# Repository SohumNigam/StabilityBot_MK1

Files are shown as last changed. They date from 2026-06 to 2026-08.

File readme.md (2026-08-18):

# StabilityBot MK1

*Currently in prototype phase*

A self-balancing two-wheeled robot — an inverted pendulum stabilized
by IMU feedback and PID motor control, being built up toward full
4-state LQR control on a custom PCB.

**Full write-up / showcase:**
[sohumnigam.github.io/projects/stability_bot_MK1.html](https://sohumnigam.github.io/projects/stability_bot_MK1.html)

## Why I built this

I wanted a project that went past the usual "balance a robot with a
PID loop" hobby build — something that let me go deep on control
theory (state-space modeling, LQR, Kalman filtering), embedded
firmware, and PCB design all at once, and end up with a portfolio
piece that shows that depth rather than just a demo video. The
long-term goal is a robot that balances using a full 4-state LQR
controller (θ, θ̇, x, ẋ) on hardware I designed myself, with a
classical-vs-learned comparison against a reinforcement learning
controller down the line.

## Photos

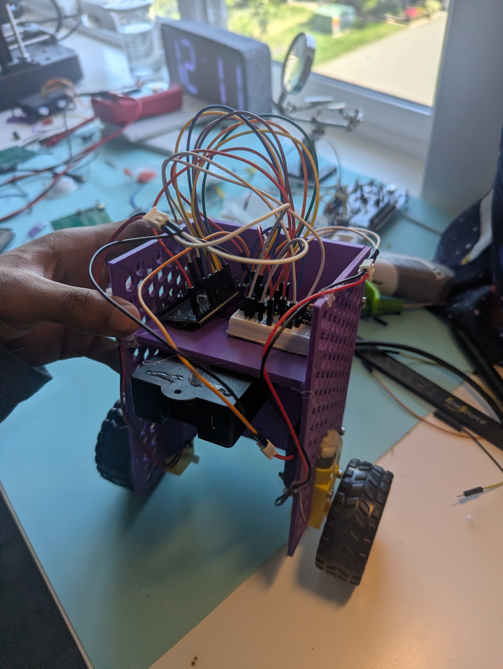
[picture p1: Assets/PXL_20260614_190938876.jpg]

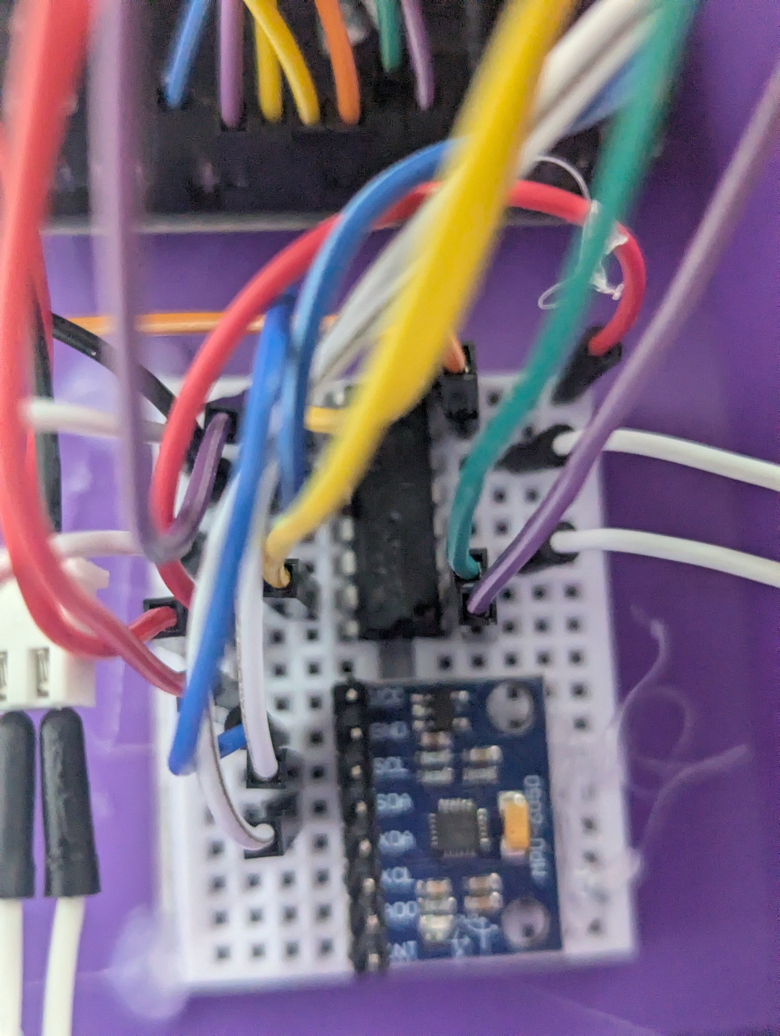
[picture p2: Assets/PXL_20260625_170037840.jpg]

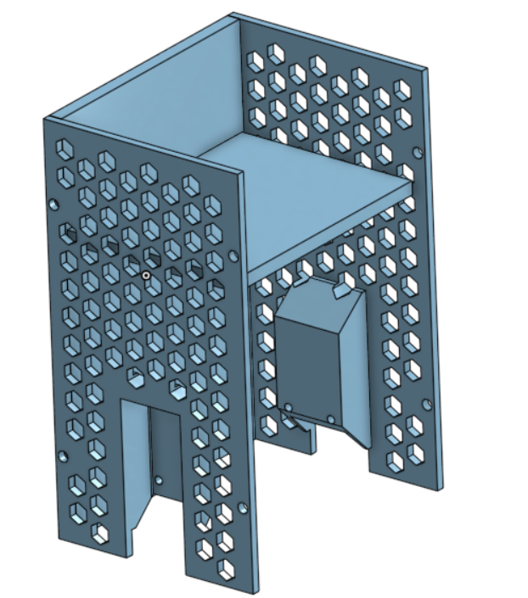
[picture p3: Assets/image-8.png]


## Demo Video

This version used PID to validate the hardware setup and learn about basic control theory. 



Will implement LQR in the future.

## Current Wiring Diagram (Subject to change)
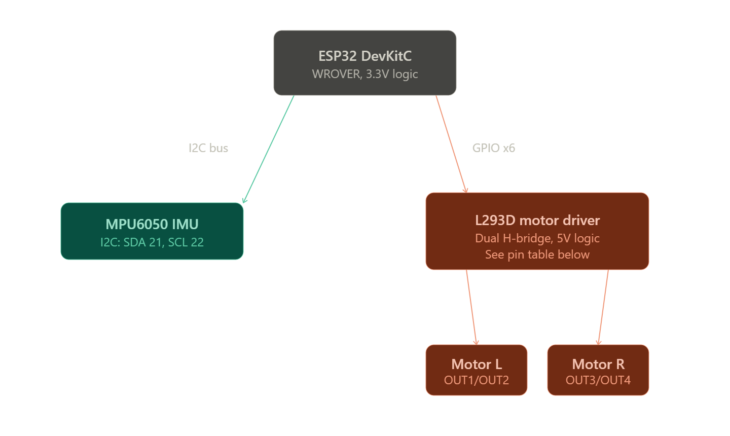
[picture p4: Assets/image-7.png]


## Future Diagram
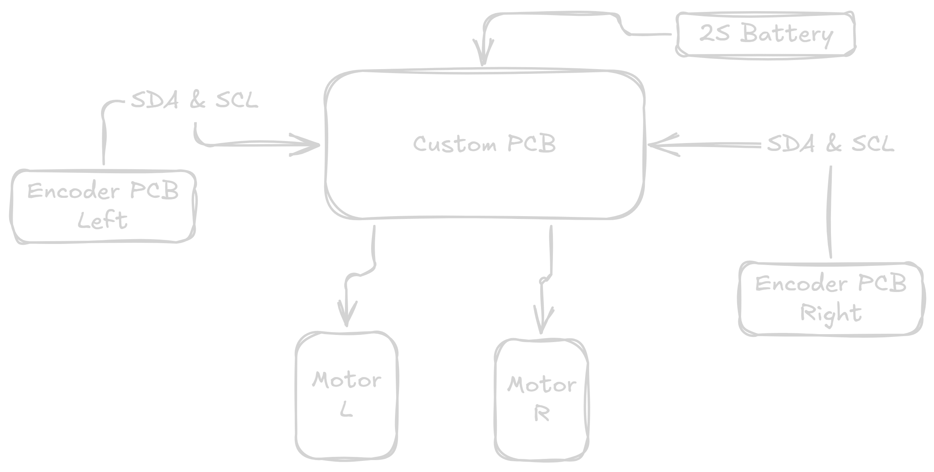
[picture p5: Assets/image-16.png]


## Current Features

- Active motor balancing response
- IMU sensor fusion (complementary filter, Kalman filter in progress)
- PID control loop
- Live web dashboard (WebSocket telemetry: pitch, motor output, PID
  tuning sliders) served from the ESP32 in SoftAP mode

## Hardware Overview

| Component | Current | Planned Upgrade |
|---|---|---|
| Compute | ESP32 Devboard | - |
| IMU | MPU6050 | Bosch BMI320 (SPI) |
| Motor driver | L293D | TB6612FNG |
| Motors | Standard yellow DC geared motors | — |
| Battery | ELEGOO battery pack | Will be compatible with any 2s Battery |
| Chassis | 3D printed | — |
| Encoders | None | AS5600 |

## Software Overview

**FreeRTOS control task**
- IMU readings
- PID calculations (LQR planned once encoders are integrated)
- Motor PWM control

**FreeRTOS web interface task**
- Digital logging
- Mobile control
- Remote PID tuning

## How to Assemble

<!-- TODO: fill in with real steps once chassis/wiring is finalized -->
1. 3D print the chassis (files: hardware/cad/step)
2. Mount motors and wheels using the screws that come with the yellow motors
3. Wire IMU, motor driver, and battery to the ESP32 per the defined pins in main.c (you will need to look in the motor structs for them)
4. Secure battery pack and IMU to minimize vibration noise. I used hot glue for this version.

## How to Flash

1. Clone this repo into your ESP-IDF project directory
2. Confirm your wiring matches the pin assignments in `main/`
3. Build and flash with `idf.py build flash monitor`
4. Connect to the robot's WebSocket dashboard to tune PID live

## Rough Bill of Materials

See the full BOM in BOM.csv. Still a work in progress as some passive parts are not yet finalized.

| Category | Qty | Part | Value | LCSC Part # | Price/unit | Extended Description | Link |
|---|---|---|---|---|---|---|---|
| Compute | 1 | ESP32 WROVER DevKitC | Espressif ESP32-WROVER-DevKitC | $11 | — | Purchased from DigiKey | [DigiKey](https://www.digikey.com/en/products/detail/espressif-systems/ESP32-DEVKITC-VIE/12091811) |
| IMU | 1 | BMI320 IMU | Bosch BMI320 | C22391148 | $0.99 | SPI IMU | [LCSC](https://www.lcsc.com/product-detail/C22391148.html) |
| Mechanics | 2 | Diametric Magnets | — | — | — | Will try to find (Hard to find affordable sources) | [Amazon](https://www.amazon.com/Diametrically-Magnetized-Neodymium-Permanent-Magnet/dp/B0GWXBS6SM) |
| Encoder | 1 | AS5600 Magnetic Encoder | AMS AS5600 | C499458 | $1.1855 | For wheel position tracking | [LCSC](https://www.lcsc.com/product-detail/C499458.html) |
| Motor Driver | 1 | TB6612FNG Motor Driver | Toshiba TB6612FNG | C141517 | $1.1659 | Target PCB driver; STBY tied to GPIO | [LCSC](https://www.lcsc.com/product-detail/C141517.html) |
| Mechanical | 2 | DC Gear Motors | — | $20 | — | Includes wheels | [Amazon](https://www.amazon.ca/SazkJere-Geared-Motor-Gearbox-200RPM/dp/B0G64KFYPS) |
| Mechanical | 1 | Chassis / Frame (custom) | — | — | — | Onshape CAD; STEP in `hardware/cad/step/` | — |

Full robot rough cost ~$170 + shipping

## Known Issues

- IMU signal occasionally drops out on the current breadboard
  prototype — traced to noise from jumper wire connections; largely
  mitigated with twisted GND pairs and a control-loop delay, but not
  fully eliminated. Root fix is the move to a soldered BMI320 board
  and eventually the custom PCB.
- 4-state LQR not yet running on hardware — pending encoder
  integration.

## Credits

- Built on [ESP-IDF](https://github.com/espressif/esp-idf) (Espressif)

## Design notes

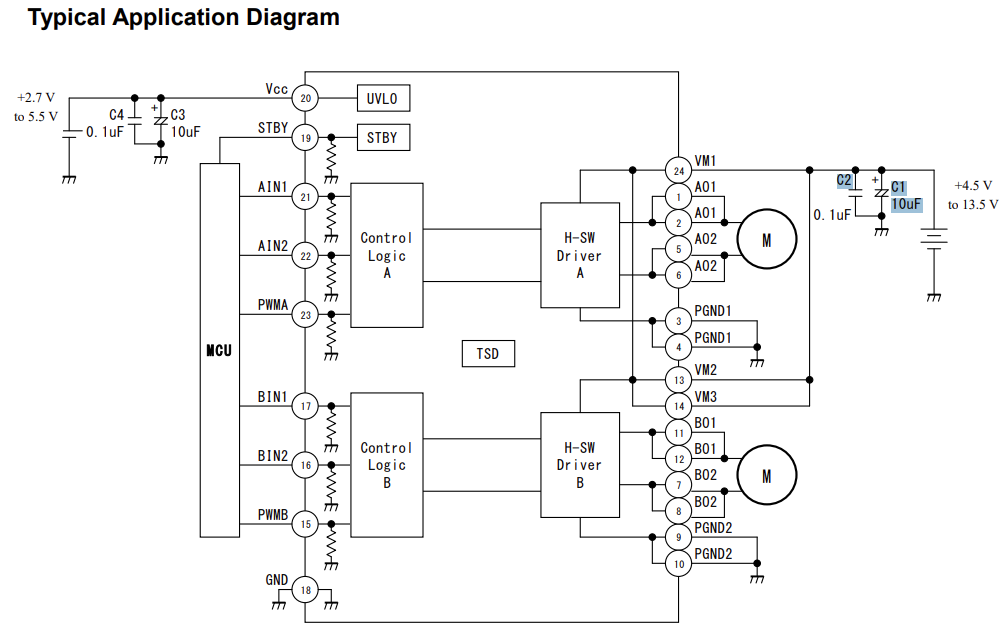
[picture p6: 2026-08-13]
hardware/PCB/TB6612FNG/Assets/Screenshot 2026-07-19 144515.png

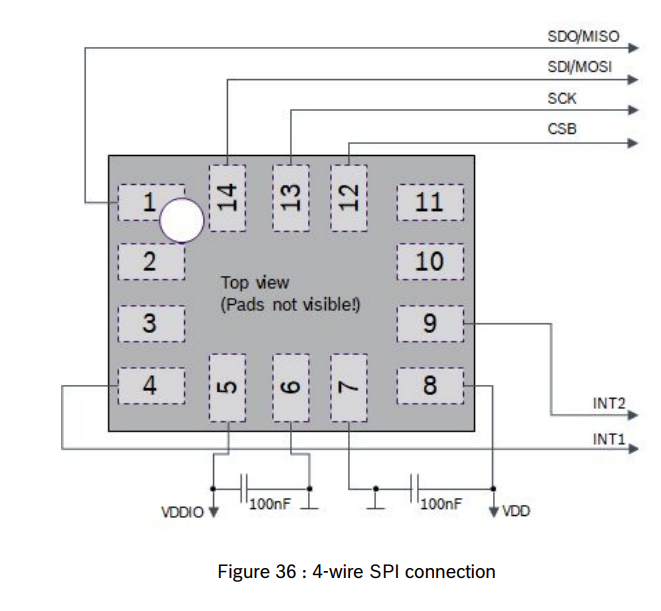
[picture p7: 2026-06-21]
Assets/BMI320_Circuit_Diagram.png

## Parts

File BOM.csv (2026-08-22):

Category | Qty | Part | Value | LCSC Part number | Price/unit | Extended description | Link
Compute | 1 | ESP32 WROVER DevKitC | Espressif ESP32-WROVER-DevKitC |  | $12 | Purchased from digikey | https://www.digikey.com/en/products/detail/espressif-systems/ESP32-DEVKITC-VIE/12091811
IMU | 1 | BMI320 IMU | Bosch BMI320 | C22391148 | $0.99 | SPI IMU | https://www.lcsc.com/product-detail/C22391148.html
Passive | 4 | Capacitor | 100nf | C49678 | $ 0.0218 |  | https://www.lcsc.com/product-detail/C49678.html
Mechanics | 2 | Diametric magnets |  |  |  | Will try to find | https://www.amazon.com/Diametrically-Magnetized-Neodymium-Permanent-Magnet/dp/B0GWXBS6SM?th=1
Encoder | 1 | AS5600 Magnetic Encoder | AMS AS5600 | C499458 | $ 1.1855 | For wheel pos tracking | https://www.lcsc.com/product-detail/C499458.html
 | 1 | Capacitor | 1uf | C28323 | $0.04 |  | https://www.lcsc.com/product-detail/C28323.html?s_z=n_q_t_1uf%25200805
Motor Driver | 1 | TB6612FNG Motor Driver | Toshiba TB6612FNG | C141517 | $ 1.1659 | Target PCB driver; STBY tied to GPIO (to purchase) | https://www.lcsc.com/product-detail/C141517.html
Passive | 2 | Tantalum Capacitor | 10uf | C117023 | $0.31 |  | https://www.lcsc.com/product-detail/C117023.html
Mechanical | 7 | Female header |  | C40877 | $0.09 | To plug in esp32 devboard | https://www.lcsc.com/product-detail/C40877.html
Mechanical | 5 | Male headers |  | C49257 | $ 0.0272 |  | https://www.lcsc.com/product-detail/C49257.html
Mechanical | 2 | DC Gear Motors |  |  | $25 | Includes Wheels | https://www.amazon.ca/SazkJere-Geared-Motor-Gearbox-200RPM/dp/B0G64KFYPS?s=industrial
Mechanical | 1 | Chassis / Frame (custom) |  |  |  | Onshape CAD; STEP in hardware/cad/step/
 |  |  |  |  | TOTAL COST | Sum of (Qty x Price/unit) across all rows

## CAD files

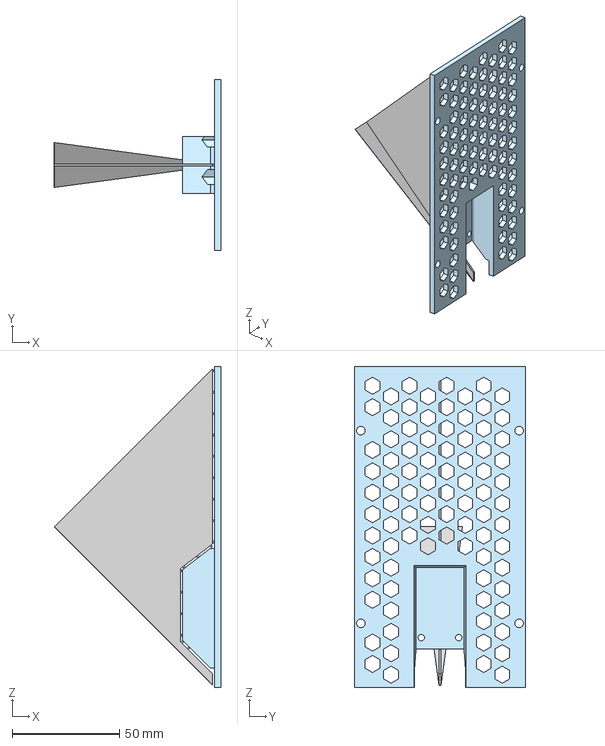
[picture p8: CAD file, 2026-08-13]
hardware/CAD/STEP/Side Plates.step
78.0 x 80.0 x 150.0 mm

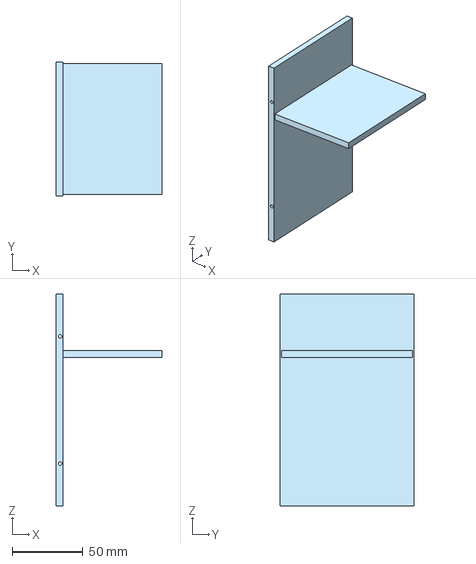
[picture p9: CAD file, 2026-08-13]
hardware/CAD/STEP/Back Plate - Plate.step
75.0 x 95.0 x 150.0 mm

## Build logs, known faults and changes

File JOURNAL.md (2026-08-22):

---
title: "StabilityBot MK1"
author: "sohum"
description: "Self-balancing inverted pendulum robot on ESP32-S3, working toward full 4-state LQR control with a custom PCB"
created_at: "2026-06-10"
---

# Before logging began: Initial concept and first assembly

Built the initial concept with basic IMU-to-motor response firmware
(no PID, no testing chassis yet). Hit the first major bug: the ESP32
boot-looped due to noise on boot GPIO pin 14 — solved by migrating
motor control to pin 25. Iterated quickly on a testing chassis design
in Onshape, then completed the first full assembly of the robot.

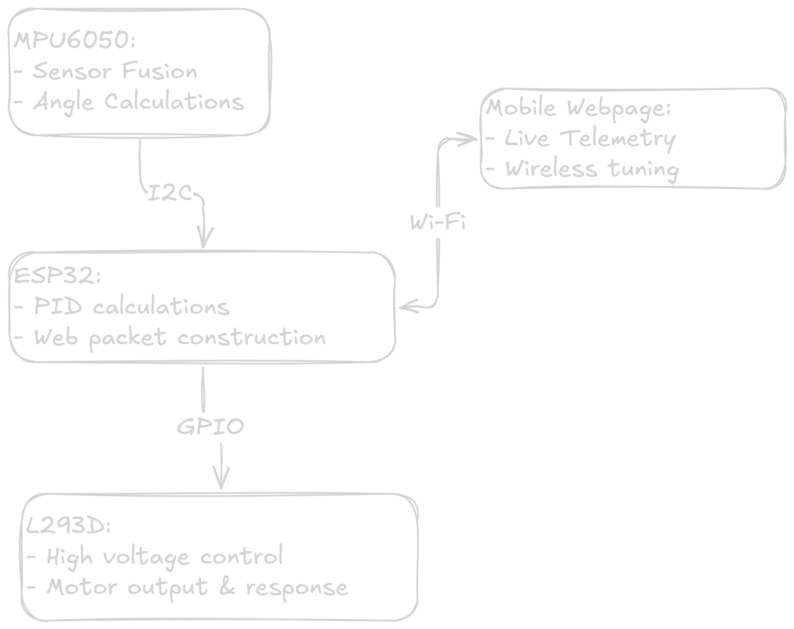
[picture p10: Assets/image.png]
logic diagram


**Total time spent: 8 hours**

# June 10: First balancing test, MPU6050 signal dropouts

Goal: gather initial test results before upgrading to more reliable hardware.

Ran the first balancing test and tried to tune PID. The MPU6050
sensor signal repeatedly cut out, causing laggy, intermittent motor
response. Impossible to tune or balance as a result.

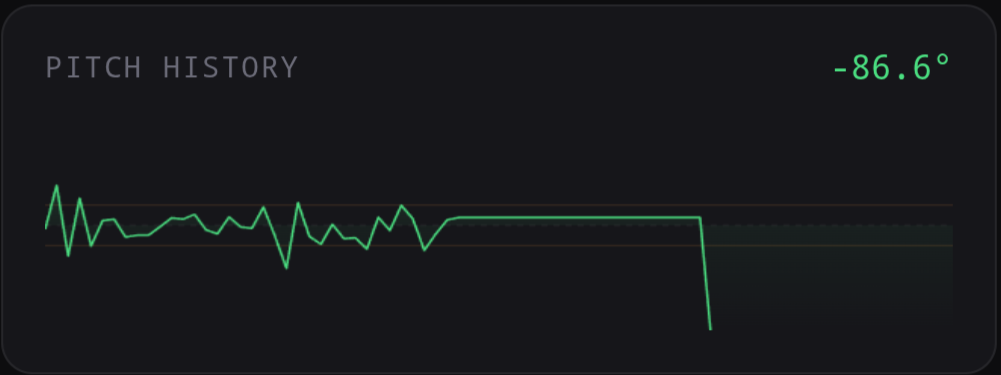
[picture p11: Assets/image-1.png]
signal dropout


Suspected cause: the current breadboard prototype and jumper wire
connections are introducing mechanical and electrical noise, causing
signal drops.

Next step: design and order a BMI320 breakout board and solder
connections to the ESP32 to eliminate testing noise.

**Total time spent: 2 hours**

# June 14: Noise mitigation on the current setup

Goal: investigate what can be done to minimize noise with the
current setup, with intent to carry the findings into the future
design even after the hardware changes.

- Twisted signal wires with GND to reduce noise
- Tuned the complementary filter to smooth the angle estimate

Both changes lowered high-frequency noise and smoothed robot motion.
Signal dropouts still persist, further supporting the need for a
custom PCB.

before:
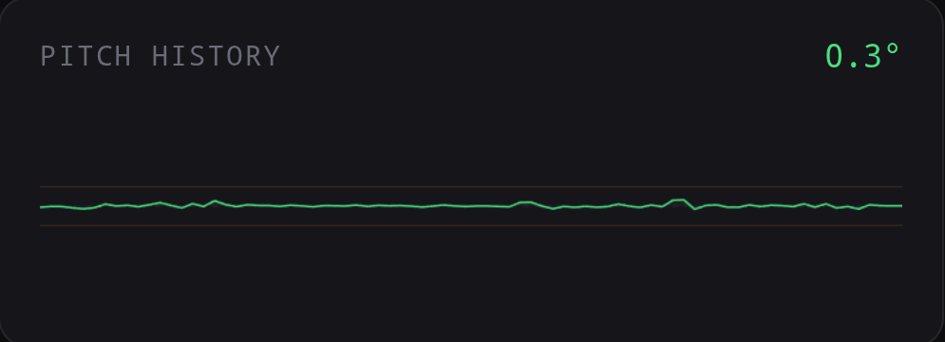
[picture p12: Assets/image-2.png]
noisy imu


after:
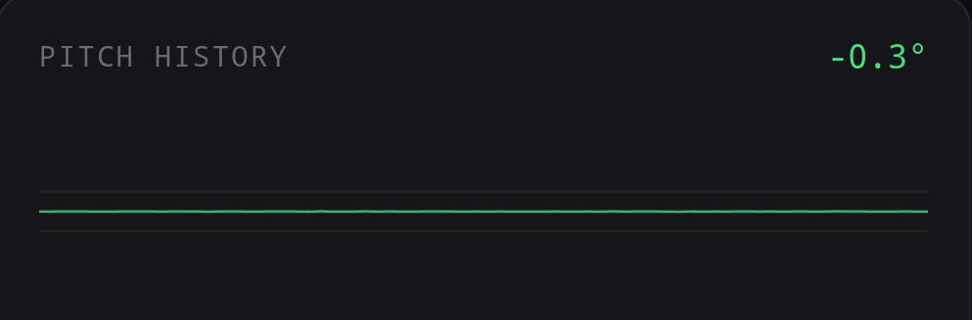
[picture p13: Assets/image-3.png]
smooth imu


**Total time spent: 1 hour**

# June 20: Chasing a software cause for signal dropout

Goal: investigate potential software causes for signal dropout.
signal dropout

- Disabled the motors
- Printed IMU readings to the serial console for debugging
- Discovered occasional watchdog timer triggers
- Added a delay to the control loop

The added delay *significantly* reduced signal dropouts during
balancing, making tuning noticeably easier. Dropouts still occur
sparsely but are much more under control now, allowing balancing
attempts to come much closer to succeeding.

**Total time spent: 2 hours**

# July 19: Custom BMI320 driver and board complete, PCB subsystems in design

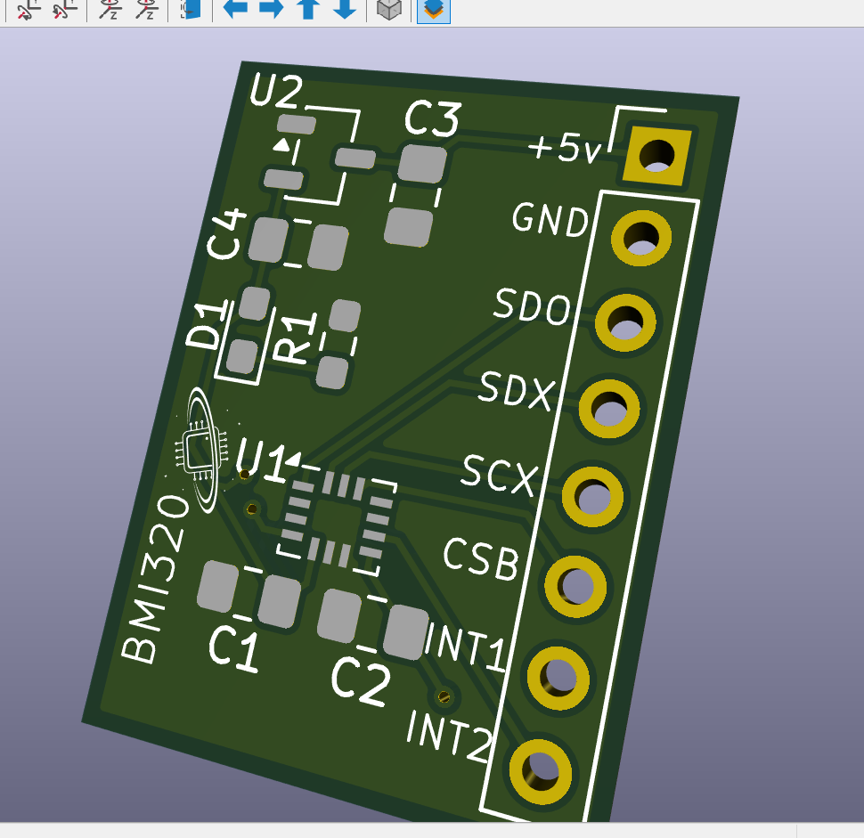
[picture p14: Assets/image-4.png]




BMI320 board debugging is complete and fully functioning. Root cause
was a disconnected VDDIO pin, which prevented the chip from powering
up properly. BMI320 driver firmware is nearing completion and cleanup.

PCB subsystem test boards are now in design (MCU, motor driver,
encoders). Encoders will be used to implement full 4-state LQR control.

Next: reach a fully functioning, fully integrated PCB and begin LQR
implementation.

LQR is short for Linear Quadratic Regulator and is the industry standard for optimal control in state space systems.

Credit to this paper from MIT that helped me learn it:
https://underactuated.mit.edu/lqr.html

**Total time spent: 4 hours**

# Aug 13: PCB subsystems combined into one schematic, Final PCB in design

Combined PCB subsystems into one schematic. Had to resolve a few pin conflicts

BMI320 IMU

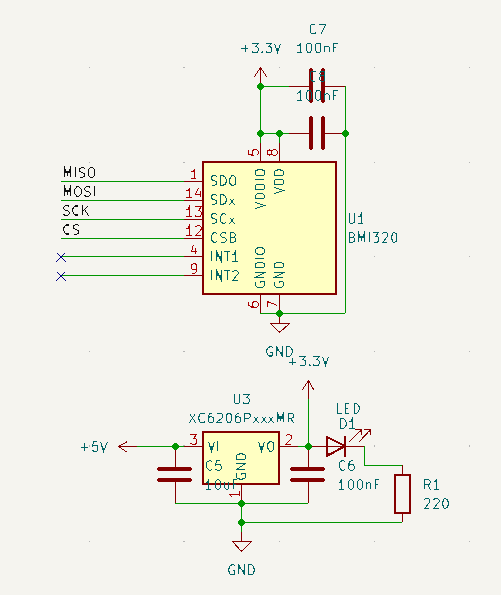
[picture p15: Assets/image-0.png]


Motor driver
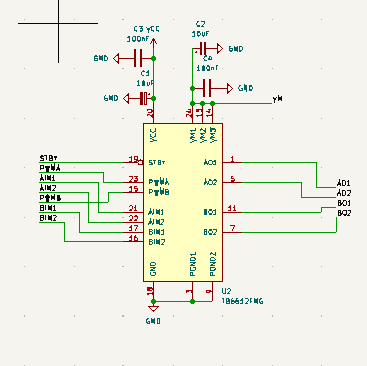
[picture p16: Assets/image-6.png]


Will move on to finalizing and reviweing connections. The start routing the final PCB.
Next steps will be to also finalize magnetic rotary encoder PCB and implement a cad mounting solution. To actually enable Full 4 state LQR control. I have high hpes for the stability of the final robot. Should be significantly more effective than PID.

**Total time spent: 1 hours**

# Aug 16: Putting together a tentative BOM, finalizing schematic, and going down the LQR rabbit hole

While the project is still in progress and not all parts are finalized, I still chose to put together a rough BOM to start to have an idea of what is pending and what can move forward.

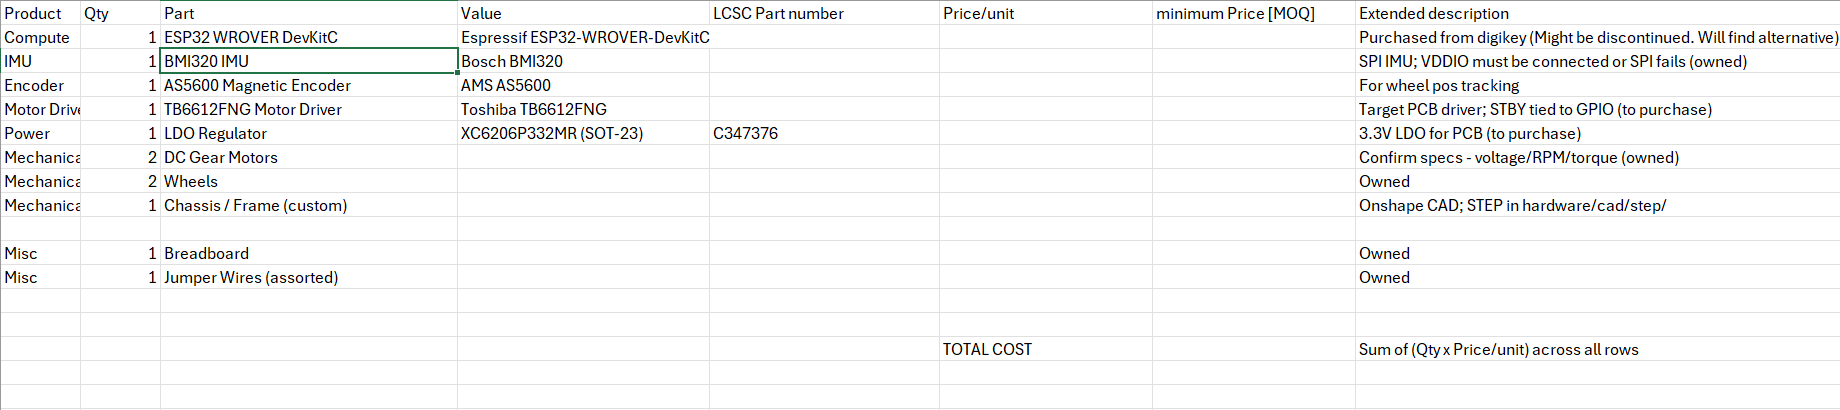
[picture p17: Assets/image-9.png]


Was a pain but I found the exact model of the esp32 board I used without even having it on me (Im on vacation) for the PCB. Also has been added to BOM

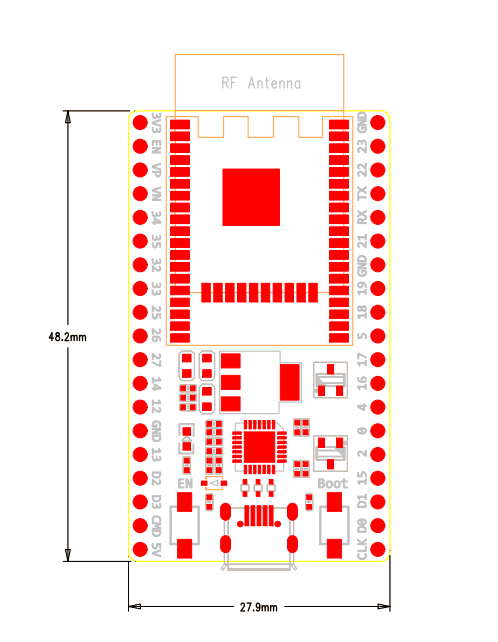
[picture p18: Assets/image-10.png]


With this newfound knowledge, I started finalising the Schematic now that parts are confirmed (just not passive components yet). Super messy rign now will make sure to do LOTS of double checking because I rlly want this to work first try or I might not finish the project in time.

Finalized the schematic!

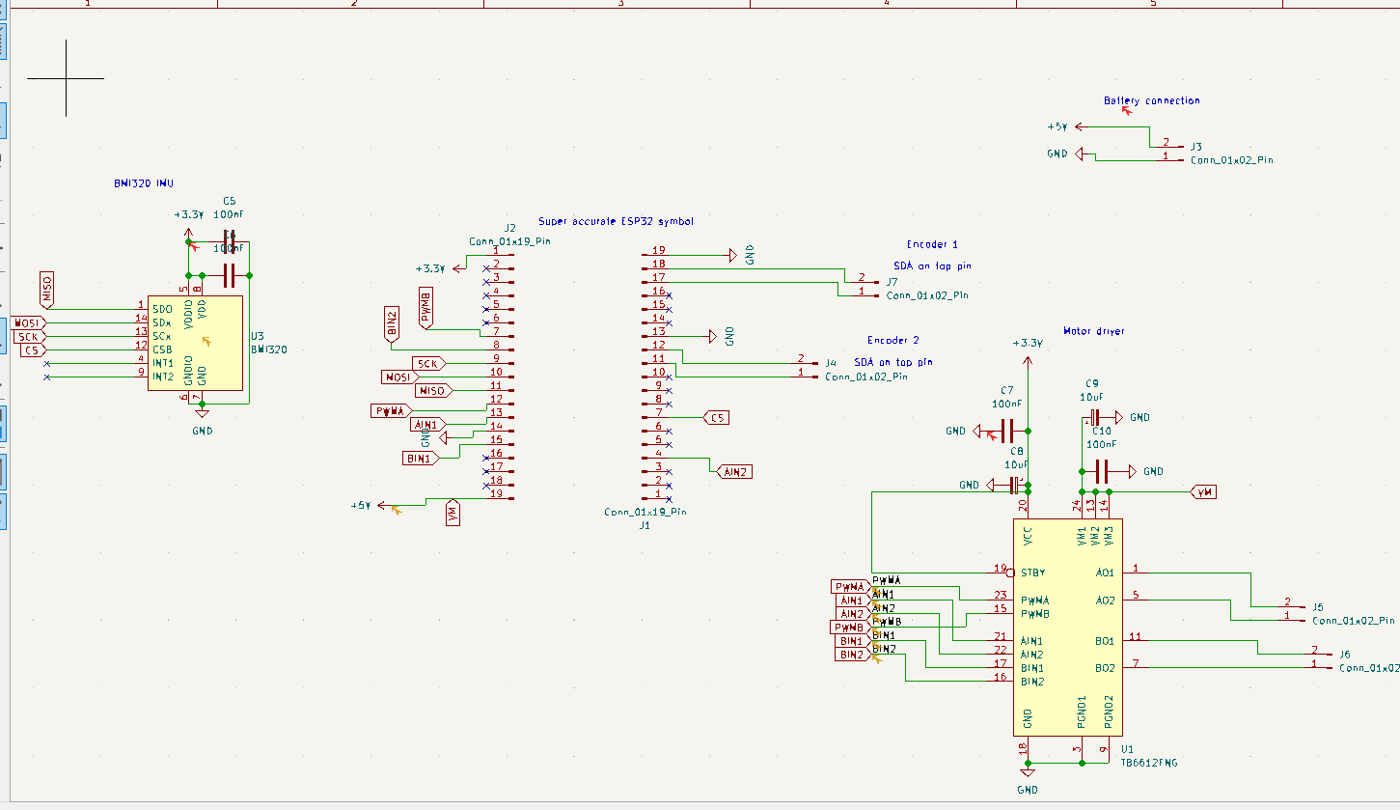
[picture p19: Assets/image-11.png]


Still needs to be revieved and double checked but should be moving on the layout in a day or 2.

Also finished encoder PCB design.

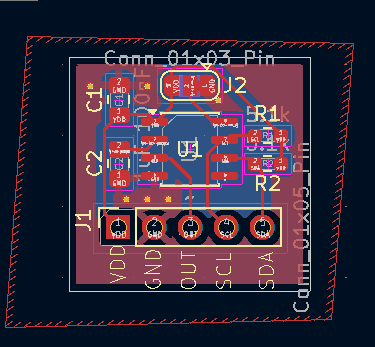
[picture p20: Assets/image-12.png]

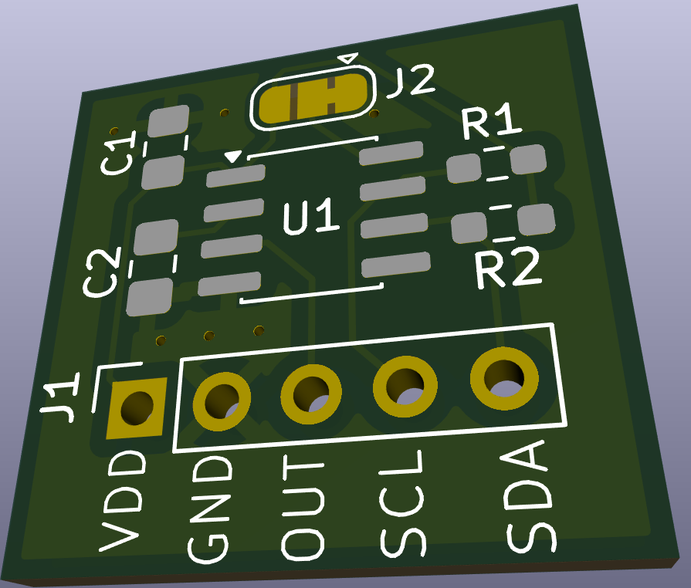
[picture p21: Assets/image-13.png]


Started working on LQR formulas derivation and simulation. Lots of juicy high level math.

The first thing I did was put together what essentially is a simplified writeup covering how LQR will be implmented specifically in my project. There is a lot I don't yet know so expect updates as I learn more about LQR.

To see my writeup about the math behind LQR, go to docs/LQR.md

**Total time spent: 5 hours**

# Aug 17: PCB layout and Started V2 CAD Model

Heres the Layout for the final PCB. Have not reviewed or added silkscreen touchups yet.

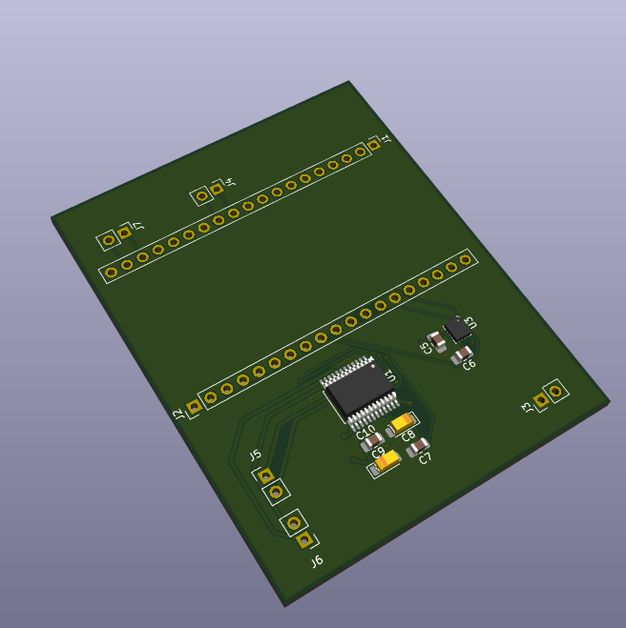
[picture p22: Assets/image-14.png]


Also started designing a sleeker cad model designed to hould the PCB, motors, and battery.
I had to do this without having any of the parts on hand so I also had to spend some time looking online for part dimensions. 

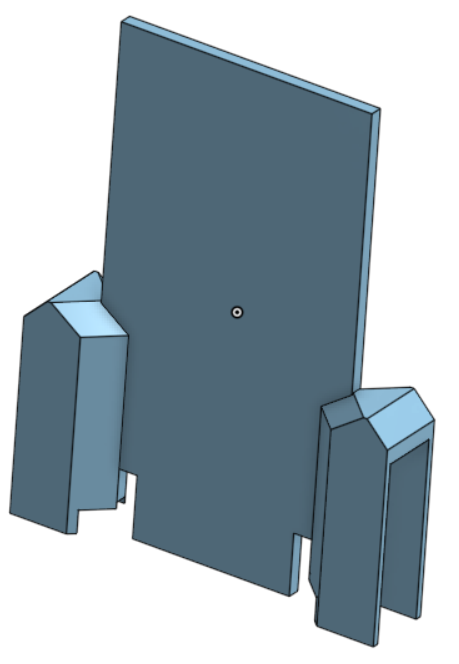
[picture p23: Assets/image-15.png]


Im trying to design the PCB and CAD in paralel to make sure the overall robot is as well put together as possible.

**Total time spent: 2 hours**

# Aug 18: Finalized the PCB!

After triple checking the schematic I polished and cleaned up the PCB layout and it is now ready to order.

I think it looks great!

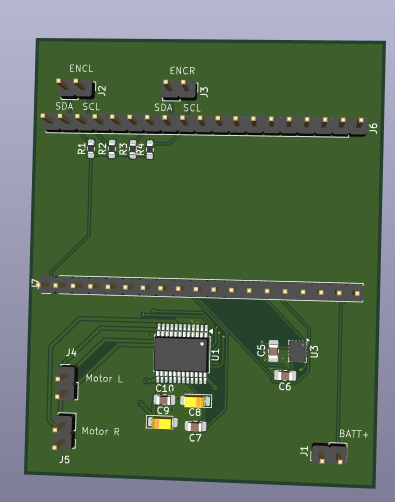
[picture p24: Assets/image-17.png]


Im planning to order it in black to lean into the liquorice theme. Maybe I'll print it with red accents as well I feel like that could look really cool.

I also spent some time working on my readme and BOM to make sure it meets the review requirments.

The BOM only is missing passive components now which will be added soon as I already have them added to my LCSC cart.

Next I need to review the encoder PCB and finally order everything.

**Total time spent: 1 hours**

# Aug 22: Ordered PCBs and almost finished BOM

I ordered both the main PCB board and encoder PCB in black and red respectivley to lean into the Liquorice theme. Honestly I dont think it will look that good but we will have to see

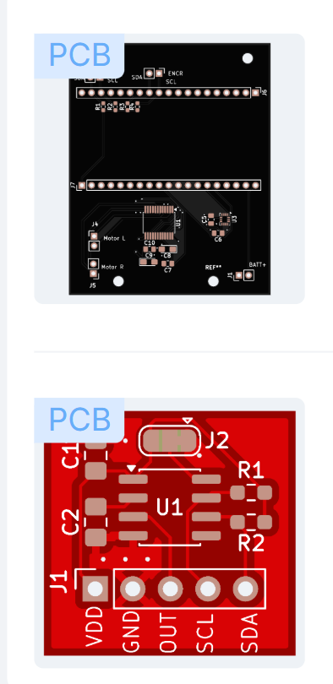
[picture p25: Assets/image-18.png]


**Total time spent: 1 hours**

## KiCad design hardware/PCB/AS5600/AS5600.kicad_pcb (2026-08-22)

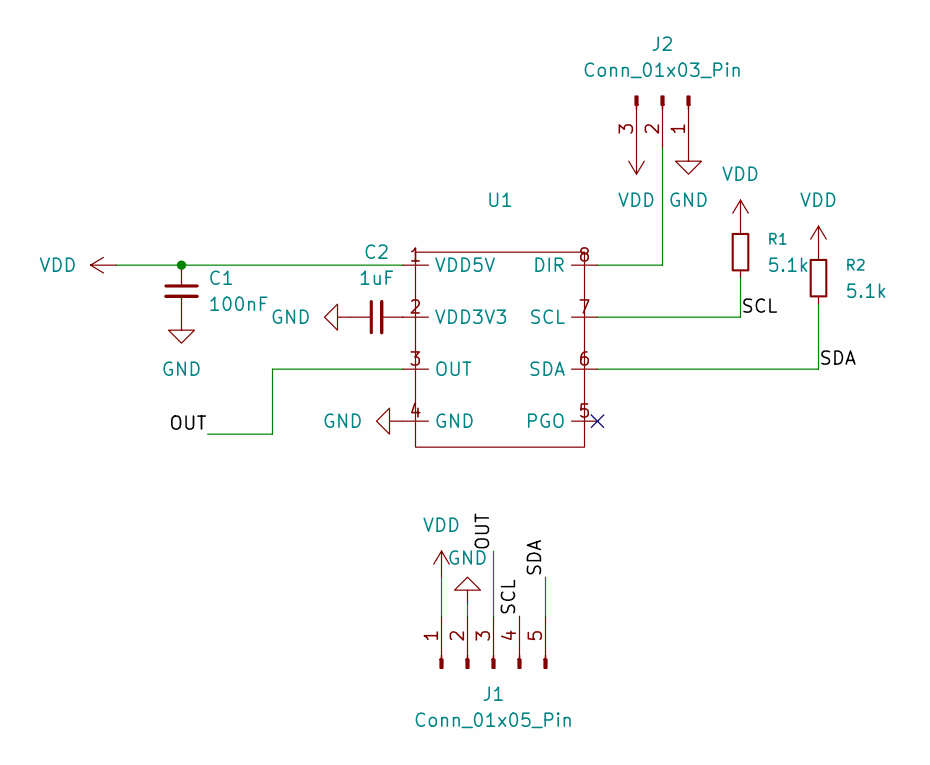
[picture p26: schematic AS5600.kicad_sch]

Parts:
C1: 100nF; C_0805_2012Metric_Pad1.18x1.45mm_HandSolder
C2: 1uF; C_0805_2012Metric_Pad1.18x1.45mm_HandSolder
J1: Conn_01x05_Pin; PinSocket_1x05_P2.54mm_Vertical
J2: Conn_01x03_Pin; SolderJumper-3_P1.3mm_Bridged12_RoundedPad1.0x1.5mm
R1, R2: 5.1k; R_0603_1608Metric_Pad0.98x0.95mm_HandSolder
U1: SOIC-8_3.9x4.9mm_P1.27mm

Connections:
/OUT: J1.3, U1.3 (OUT)
/SCL: J1.4, R1.2, U1.7 (SCL)
/SDA: J1.5, R2.2, U1.6 (SDA)
GND: C1.2, C2.1, J1.2, J2.1, U1.4 (GND)
unnamed: J2.2, U1.8 (DIR)
unnamed: C2.2, U1.2 (VDD3V3)
VDD: C1.1, J1.1, J2.3, R1.1, R2.1, U1.1 (VDD5V)

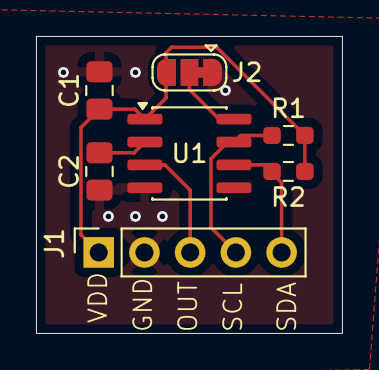
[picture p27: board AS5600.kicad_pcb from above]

Board: 2 copper layers, 17.0 x 16.5 mm, 7 parts (0 on the bottom side), 7 nets.

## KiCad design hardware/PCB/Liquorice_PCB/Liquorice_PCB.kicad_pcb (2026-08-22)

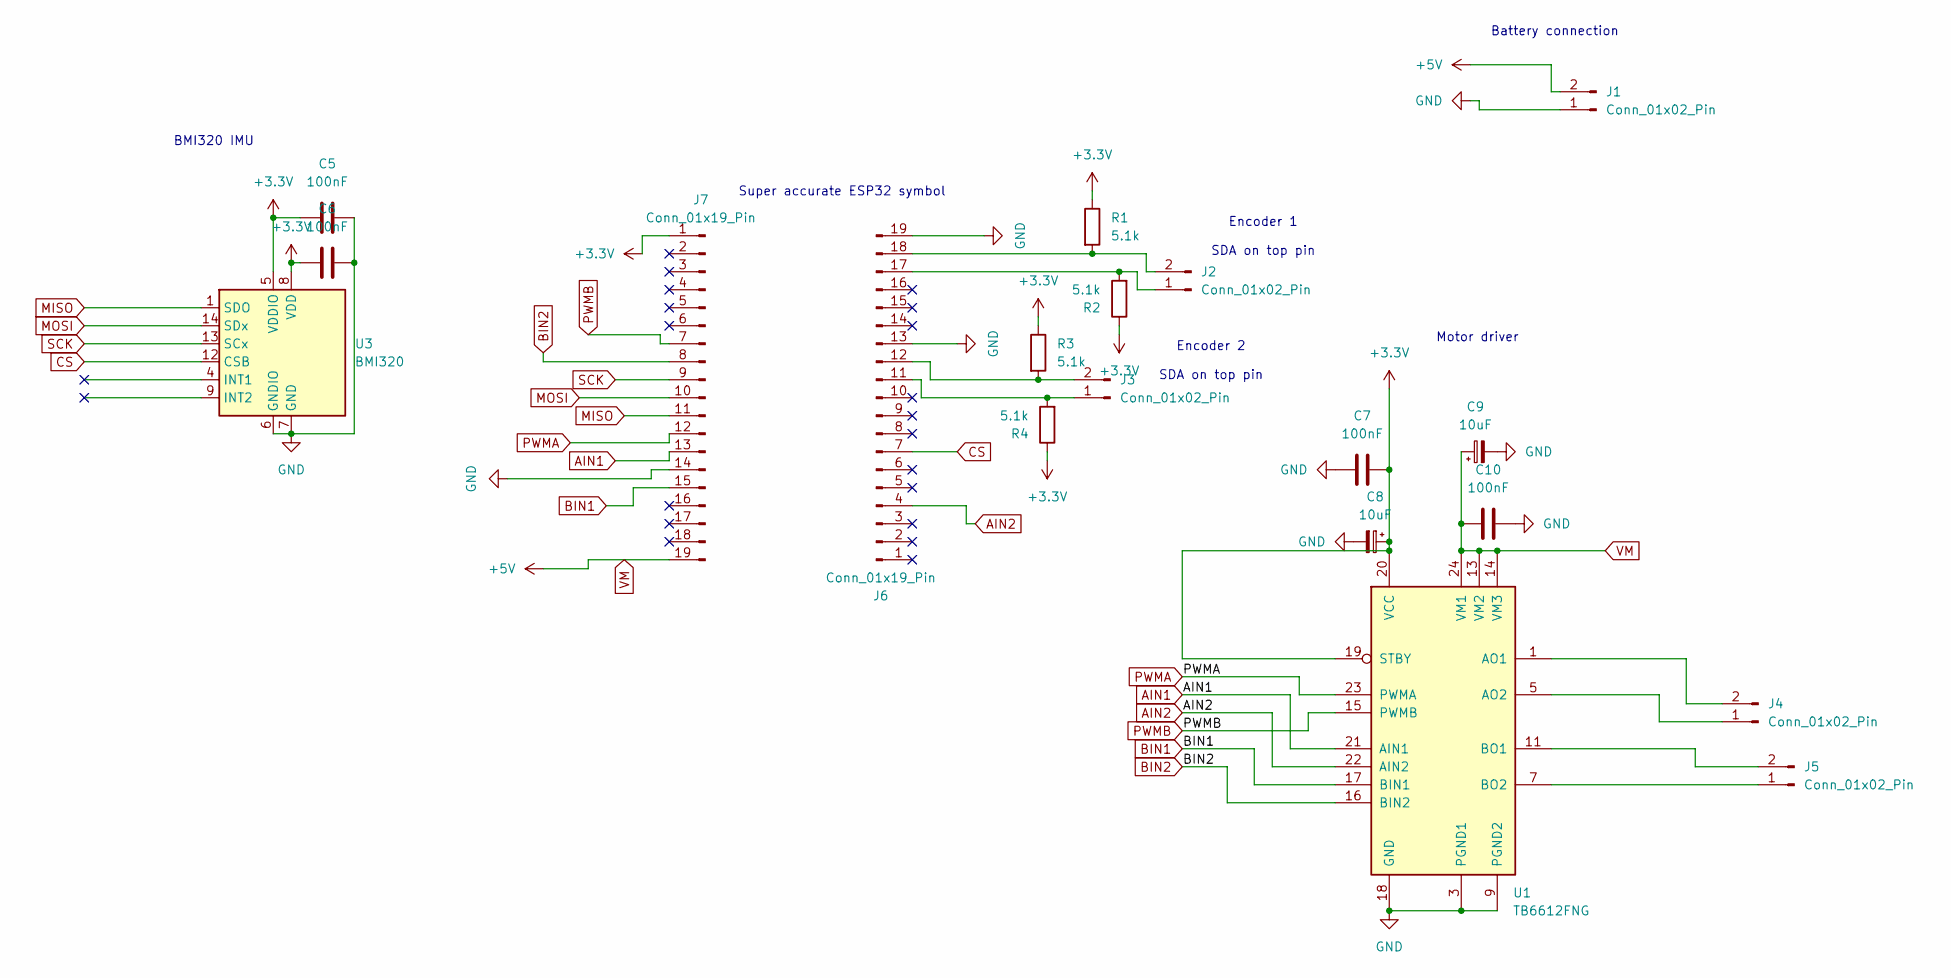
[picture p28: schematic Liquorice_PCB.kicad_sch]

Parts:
C5, C6, C7, C10: 100nF; C_0805_2012Metric_Pad1.18x1.45mm_HandSolder
C8, C9: 10uF; CP_EIA-3216-18_Kemet-A_HandSolder
J1, J2, J3, J4, J5: Conn_01x02_Pin; PinHeader_1x02_P2.54mm_Vertical
J6, J7: Conn_01x19_Pin; PinHeader_1x19_P2.54mm_Vertical
R1, R2, R3, R4: 5.1k; R_0603_1608Metric_Pad0.98x0.95mm_HandSolder
U1: TB6612FNG; SSOP-24_5.3x8.2mm_P0.65mm
U3: BMI320; Bosch_LGA-14_3x2.5mm_P0.5mm

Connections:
+3.3V: C5.1, C6.1, C7.2, C8.1, J7.1, R1.1, R2.1, R3.1, R4.1, U1.19 (STBY), U1.20 (VCC), U3.5 (VDDIO), U3.8 (VDD)
AIN1: J7.13, U1.21 (AIN1)
AIN2: J6.4, U1.22 (AIN2)
BIN1: J7.15, U1.17 (BIN1)
BIN2: J7.8, U1.16 (BIN2)
CS: J6.7, U3.12 (CSB)
GND: C5.2, C6.2, C7.1, C8.2, C9.2, C10.2, J1.1, J6.13, J6.19, J7.14, U1.3 (PGND1), U1.4 (PGND1), U1.9 (PGND2), U1.10 (PGND2), U1.18 (GND), U3.6 (GNDIO), U3.7 (GND)
MISO: J7.11, U3.1 (SDO)
MOSI: J7.10, U3.14 (SDx)
unnamed: J2.1, J6.17, R2.2
unnamed: J2.2, J6.18, R1.2
unnamed: J3.1, J6.11, R4.2
unnamed: J3.2, J6.12, R3.2
unnamed: J4.1, U1.5 (AO2), U1.6 (AO2)
unnamed: J4.2, U1.1 (AO1), U1.2 (AO1)
unnamed: J5.1, U1.7 (BO2), U1.8 (BO2)
unnamed: J5.2, U1.11 (BO1), U1.12 (BO1)
PWMA: J7.12, U1.23 (PWMA)
PWMB: J7.7, U1.15 (PWMB)
SCK: J7.9, U3.13 (SCx)
VM: C9.1, C10.1, J1.2, J7.19, U1.13 (VM2), U1.14 (VM3), U1.24 (VM1)

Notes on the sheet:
Encoder 1 SDA on top pin
Motor driver
BMI320 IMU
Super accurate ESP32 symbol
Battery connection
Encoder 2 SDA on top pin

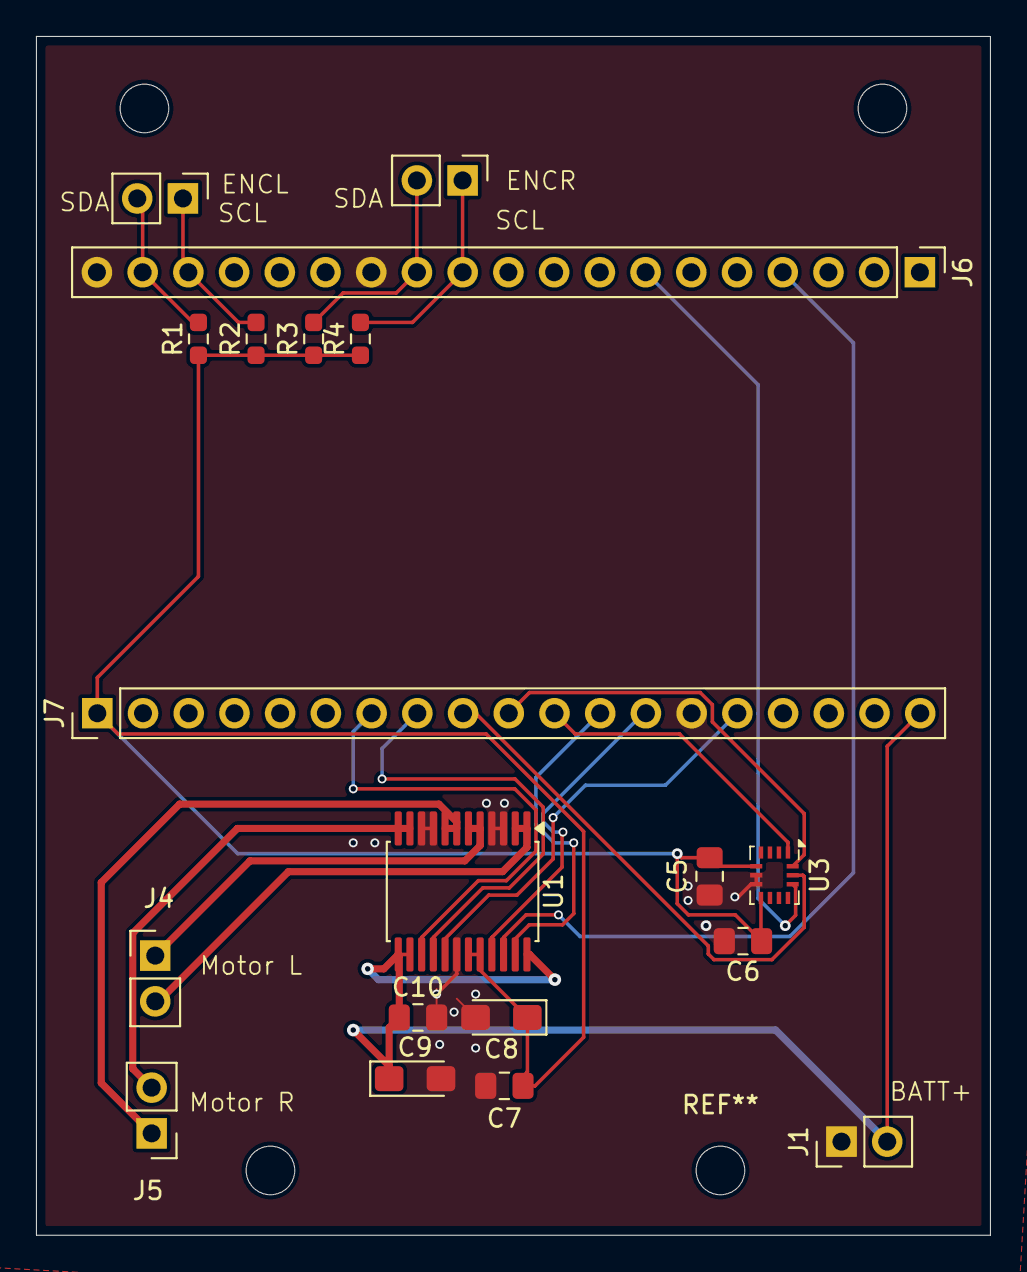
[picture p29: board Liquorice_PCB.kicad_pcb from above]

Board: 2 copper layers, 53.0 x 66.6 mm, 19 parts (0 on the bottom side), 21 nets.

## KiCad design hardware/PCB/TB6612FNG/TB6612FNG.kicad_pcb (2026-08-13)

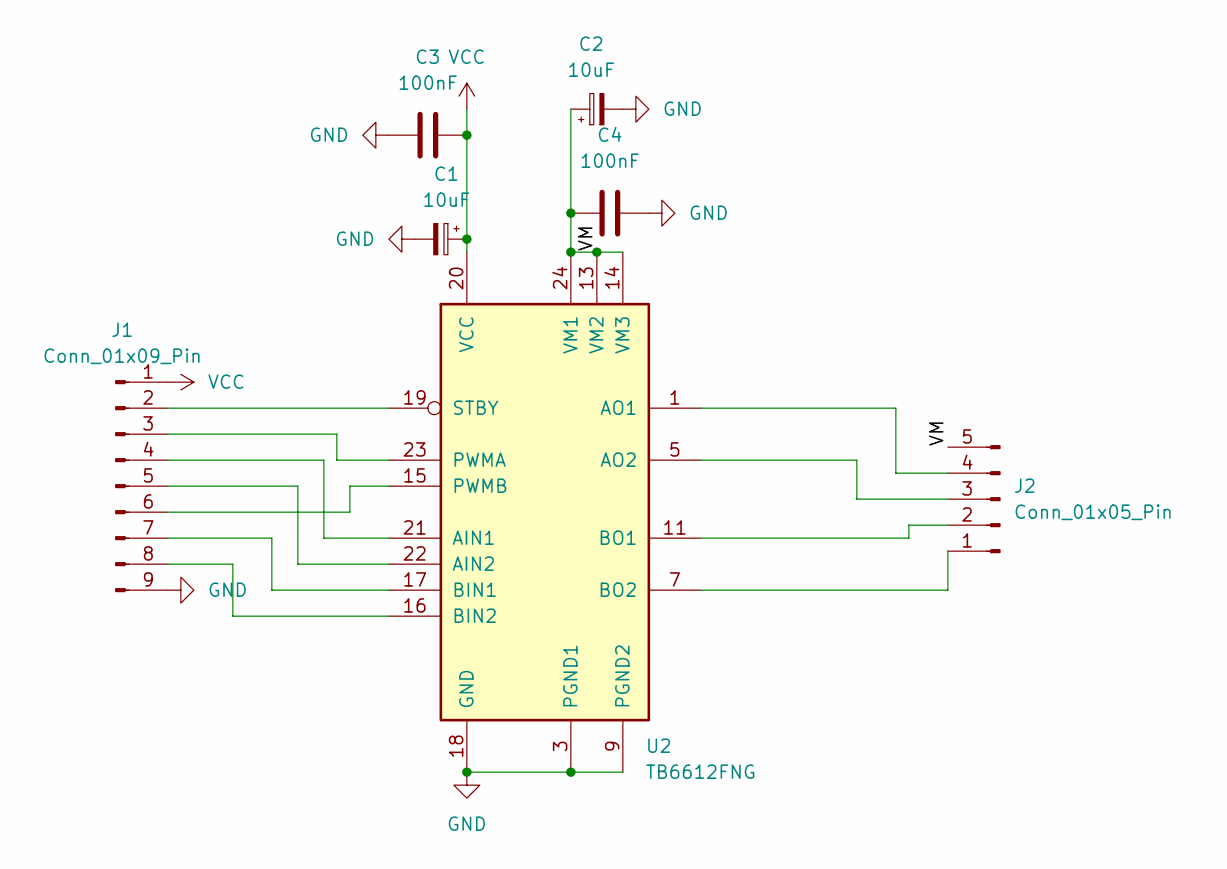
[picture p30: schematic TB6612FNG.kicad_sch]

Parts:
C1, C2: 10uF; CP_EIA-3216-18_Kemet-A_HandSolder
C3, C4: 100nF; C_0805_2012Metric_Pad1.18x1.45mm_HandSolder
J1: Conn_01x09_Pin; PinSocket_1x09_P2.54mm_Vertical
J2: Conn_01x05_Pin; PinSocket_1x05_P2.54mm_Vertical
U2: TB6612FNG; SSOP-24_5.3x8.2mm_P0.65mm

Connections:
/VM: C2.1, C4.1, J2.5, U2.13 (VM2), U2.14 (VM3), U2.24 (VM1)
GND: C1.2, C2.2, C3.1, C4.2, J1.9, U2.3 (PGND1), U2.4 (PGND1), U2.9 (PGND2), U2.10 (PGND2), U2.18 (GND)
unnamed: J1.2, U2.19 (STBY)
unnamed: J1.3, U2.23 (PWMA)
unnamed: J1.4, U2.21 (AIN1)
unnamed: J1.5, U2.22 (AIN2)
unnamed: J1.6, U2.15 (PWMB)
unnamed: J1.7, U2.17 (BIN1)
unnamed: J1.8, U2.16 (BIN2)
unnamed: J2.1, U2.7 (BO2), U2.8 (BO2)
unnamed: J2.2, U2.11 (BO1), U2.12 (BO1)
unnamed: J2.3, U2.5 (AO2), U2.6 (AO2)
unnamed: J2.4, U2.1 (AO1), U2.2 (AO1)
VCC: C1.1, C3.2, J1.1, U2.20 (VCC)

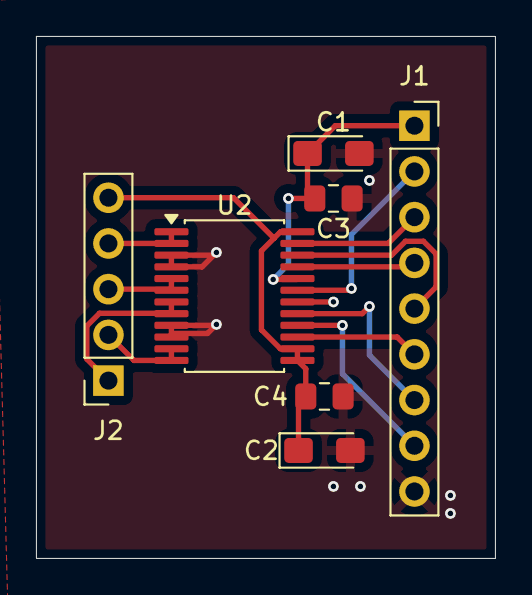
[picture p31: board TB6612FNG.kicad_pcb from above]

Board: 2 copper layers, 25.5 x 29.0 mm, 7 parts (0 on the bottom side), 14 nets.

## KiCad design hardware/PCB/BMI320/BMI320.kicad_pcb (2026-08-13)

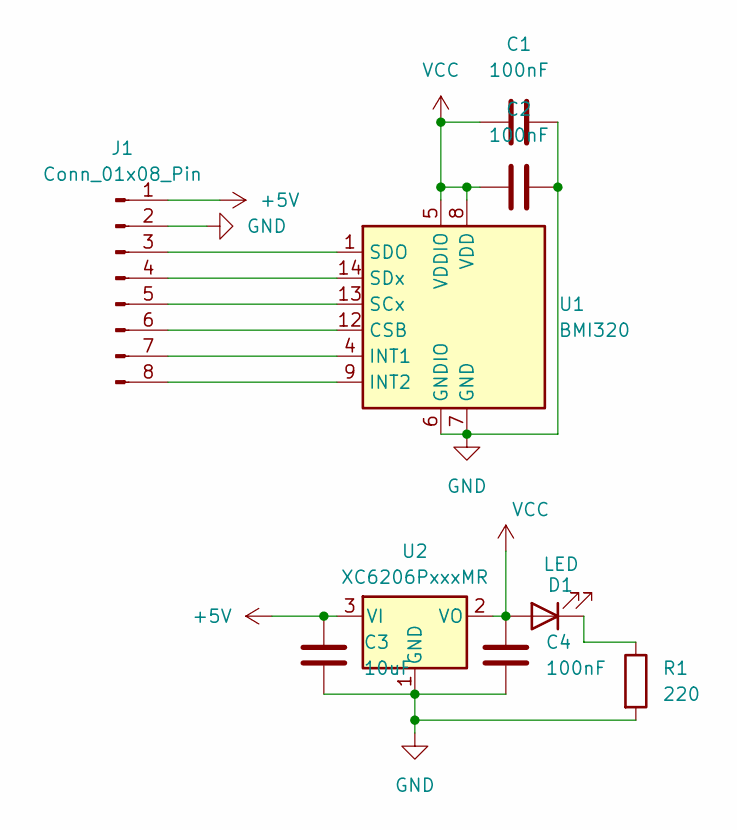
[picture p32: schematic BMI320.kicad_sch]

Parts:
C1, C2, C4: 100nF; C_0805_2012Metric_Pad1.18x1.45mm_HandSolder
C3: 10uF; C_0805_2012Metric_Pad1.18x1.45mm_HandSolder
D1: LED; LED_0603_1608Metric_Pad1.05x0.95mm_HandSolder
J1: Conn_01x08_Pin; PinHeader_1x08_P2.54mm_Vertical
R1: 220; R_0603_1608Metric_Pad0.98x0.95mm_HandSolder
U1: BMI320; Bosch_LGA-14_3x2.5mm_P0.5mm
U2: XC6206PxxxMR; SOT-23-3

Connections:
+5V: C3.2, J1.1, U2.3 (VI)
GND: C1.2, C2.2, C3.1, C4.1, J1.2, R1.2, U1.6 (GNDIO), U1.7 (GND), U2.1 (GND)
unnamed: D1.1 (K), R1.1
unnamed: J1.3, U1.1 (SDO)
unnamed: J1.4, U1.14 (SDx)
unnamed: J1.5, U1.13 (SCx)
unnamed: J1.6, U1.12 (CSB)
unnamed: J1.7, U1.4 (INT1)
unnamed: J1.8, U1.9 (INT2)
VCC: C1.1, C2.1, C4.2, D1.2 (A), U1.5 (VDDIO), U1.8 (VDD), U2.2 (VO)

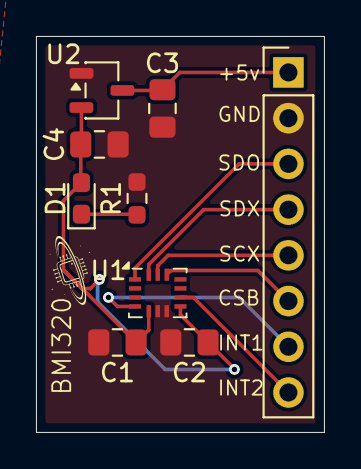
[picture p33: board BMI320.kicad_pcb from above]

Board: 2 copper layers, 16.0 x 22.0 mm, 9 parts (0 on the bottom side), 10 nets.

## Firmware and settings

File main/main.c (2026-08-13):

#include <stdio.h>
#include <esp_log.h>
#include "driver/i2c_master.h"
#include "esp_timer.h"

#include "mpu6050.h"
#include "motors.h"
#include "telemetry.h"

#include "esp_wifi.h"
#include "esp_event.h"
#include "nvs_flash.h"

#include "esp_spiffs.h"


#define WIFI_SSID "RobotAP"
#define WIFI_PASS "robot1234"

#define TAG "MAIN"

void wifi_init_softap(void) {
    nvs_flash_init();
    esp_netif_init();
    esp_event_loop_create_default();
    esp_netif_create_default_wifi_ap();

    wifi_init_config_t cfg = WIFI_INIT_CONFIG_DEFAULT();
    esp_wifi_init(&cfg);

    wifi_config_t ap_config = {
        .ap = {
            .ssid          = WIFI_SSID,
            .password      = WIFI_PASS,
            .ssid_len      = strlen(WIFI_SSID),
            .max_connection = 2,
            .authmode      = WIFI_AUTH_WPA2_PSK,
        },
    };
    esp_wifi_set_mode(WIFI_MODE_AP);
    esp_wifi_set_config(WIFI_IF_AP, &ap_config);
    esp_wifi_start();
    // Connect to http://192.168.4.1 on your phone/laptop to see telemetry data
}


void spiffs_init(void) {
    esp_vfs_spiffs_conf_t conf = {
        .base_path = "/web",
        .partition_label = "storage",
        .max_files = 5,
        .format_if_mount_failed = true
    };

    esp_err_t ret = esp_vfs_spiffs_register(&conf);
    if (ret != ESP_OK) {
        ESP_LOGE(TAG, "SPIFFS mount failed: %s", esp_err_to_name(ret));
    }
}

//mpu6050 i2c ****Need to update firmare for BMI320
#define I2C_MASTER_SDA 21
#define I2C_MASTER_SCL 22
#define I2C_MASTER_NUM I2C_NUM_0
#define I2C_MASTER_FREQ_HZ 400000

#define RAD_TO_DEG 57.2957795f

#define motor_min_speed 172 // minimum speed to overcome static friction

float Kp = 1.2f;
float Ki = 0.0f;
float Kd = 0.0f;


motor_t motor_left = {
    .channel = 0,
    .timer = 0,
    .pin_a = 26,
    .pin_b = 27,
    .en_pin = 14
};

motor_t motor_right = {
    .channel = 1,
    .timer = 1,
    .pin_a = 25,
    .pin_b = 33,
    .en_pin = 32
};






void i2c_master_init(void) {
    i2c_config_t conf = {
        .mode = I2C_MODE_MASTER,
        .sda_io_num = I2C_MASTER_SDA,
        .scl_io_num = I2C_MASTER_SCL,
        .sda_pullup_en = GPIO_PULLUP_ENABLE,
        .scl_pullup_en = GPIO_PULLUP_ENABLE,
        .master.clk_speed = I2C_MASTER_FREQ_HZ,
    };
    i2c_param_config(I2C_MASTER_NUM, &conf);
    i2c_driver_install(I2C_MASTER_NUM, conf.mode, 0, 0, 0);
}



mpu6050_data_t mpu6050_data;


static int64_t last_time = 0;

float target_angle = 0.0f;
float prev_err = 0.0f;

float total_error = 0.0f; // for integral term

int motor_speed;

void control_task(void *arg){

    
    while (1) {
        



        //IMU calclulations
        int64_t now = esp_timer_get_time();
        float dt = (now - last_time) / 1000000.0f; // convert to seconds
        last_time = now;

        if (mpu6050_read_converted(I2C_MASTER_NUM, &mpu6050_data, dt) != ESP_OK) {

            ESP_LOGE(TAG, "Failed to read MPU6050 data");
                vTaskDelay(pdMS_TO_TICKS(100));

        }else {
            //ESP_LOGI(TAG, "Pitch: %.2f°, Roll: %.2f°, Yaw: %.2f°", mpu6050_data.pitch, mpu6050_data.roll, mpu6050_data.yaw);
            
        }


        
        //PID control calculations
        float err = target_angle - mpu6050_data.pitch;
        total_error += err * dt;
        
        // Reset integral term if error changes sign
        if ((err > 0 && prev_err < 0) || (err < 0 && prev_err > 0)) {
            total_error = 0.0f;
        }

        float offset_p = Kp * err;
        float offset_i = Ki * total_error;
        float offset_d = Kd * (err - prev_err) / dt;

        // Anti-windup: Clamp the integral term
        if (offset_i > 5.0f) offset_i = 5.0f;
        if (offset_i < -5.0f) offset_i = -5.0f;



        float total_offset = offset_p + offset_i + offset_d;

        prev_err = err;
        //ESP_LOGI(TAG, "Offset: P=%.2f, I=%.2f, D=%.2f, Total=%.2f", offset_p, offset_i, offset_d, total_offset);



        //motor output 
        if (abs((int)err) > 70){
            total_offset = 0;
        }


        if(total_offset < 0) {
            motor_speed = -1 * (motor_min_speed) + (int)total_offset; // reverse direction for negative offset
        }else if(total_offset > 0) {
            motor_speed = motor_min_speed + (int)total_offset;
        }else{
            motor_speed = 0;
        }

        if (motor_speed > 255) motor_speed = 255;
        if (motor_speed < -255) motor_speed = -255;


        //ESP_LOGI(TAG, "Motor speed: %d", motor_speed);

        set_motor_speed(&motor_left, motor_speed);
        set_motor_speed(&motor_right, motor_speed);




        //telemetry update  
        if (xSemaphoreTake(g_telemetry_mutex, 0) == pdTRUE) {
            g_telemetry.pitch        = mpu6050_data.pitch;
            g_telemetry.err          = err;
            g_telemetry.p_term       = offset_p;
            g_telemetry.i_term       = offset_i;
            g_telemetry.d_term       = offset_d;
            g_telemetry.total_offset = total_offset;
            g_telemetry.motor_speed  = motor_speed;
            g_telemetry.dt_ms        = dt * 1000.0f;
            xSemaphoreGive(g_telemetry_mutex);
        }
    
        vTaskDelay(pdMS_TO_TICKS(10));

    }
}


void telemetry_task(void *arg) {
    while (1) {
        ws_broadcast_telemetry();
        vTaskDelay(pdMS_TO_TICKS(50));  // 20 Hz broadcast
    }
}


void app_main(void)
{
    
    
    i2c_master_init();
    mpu6050_init(I2C_MASTER_NUM, &mpu6050_data);
    mpu6050_calibrate(I2C_MASTER_NUM, &mpu6050_data);

    //who am i (i2c sanity check)
    uint8_t whoami;
    mpu6050_who_am_i(I2C_MASTER_NUM, &whoami);
    ESP_LOGI(TAG, "WHO_AM_I = 0x%02X", whoami);
    
    
    motor_init(&motor_left);
    motor_init(&motor_right);

    spiffs_init();

    wifi_init_softap();
    ws_server_start();
    
    xTaskCreatePinnedToCore(control_task, "control_task", 4096, NULL, 5, NULL, 0);
    xTaskCreatePinnedToCore(telemetry_task, "telemetry", 4096, NULL, 3, NULL, 1);
    
    


}

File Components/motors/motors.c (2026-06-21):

#include "motors.h"

#include "driver/gpio.h"
#include "driver/ledc.h"

#define PWM_FREQ       20000
#define PWM_RESOLUTION LEDC_TIMER_8_BIT

esp_err_t motor_init(motor_t *motor)
{
    if (motor == NULL)
        return ESP_ERR_INVALID_ARG;
        
    gpio_reset_pin(motor->pin_a);
    gpio_reset_pin(motor->pin_b);
    gpio_reset_pin(motor->en_pin);
        
    gpio_set_direction(motor->pin_a, GPIO_MODE_OUTPUT);
    gpio_set_direction(motor->pin_b, GPIO_MODE_OUTPUT);

    ledc_timer_config_t ledc_timer = {
        .speed_mode       = LEDC_LOW_SPEED_MODE,
        .timer_num        = motor->timer,
        .duty_resolution  = LEDC_TIMER_8_BIT,
        .freq_hz          = 20000,
        .clk_cfg          = LEDC_AUTO_CLK
    };

    ESP_ERROR_CHECK(ledc_timer_config(&ledc_timer));

    ledc_channel_config_t ledc_channel = {
        .gpio_num   = motor->en_pin,
        .speed_mode = LEDC_LOW_SPEED_MODE,
        .channel    = motor->channel,
        .timer_sel  = motor->timer,
        .duty       = 0,
        .hpoint     = 0
    };

    ESP_ERROR_CHECK(ledc_channel_config(&ledc_channel));




    motor->speed = 0;

    return ESP_OK;
}
esp_err_t set_motor_speed(motor_t *motor, int speed)
{
    if (!motor)
        return ESP_ERR_INVALID_ARG;

    if (speed > 255) speed = 255;
    if (speed < -255) speed = -255;

    int dir_a = 0;
    int dir_b = 0;

    if (speed > 0)
    {
        dir_a = 1;
        dir_b = 0;
    }
    else if (speed < 0)
    {
        dir_a = 0;
        dir_b = 1;
        speed = -speed;
    }
    else
    {
        dir_a = 0;
        dir_b = 0;
    }

    gpio_set_level(motor->pin_a, dir_a);
    gpio_set_level(motor->pin_b, dir_b);
    

    ledc_set_duty(LEDC_LOW_SPEED_MODE, motor->channel, speed);
    ledc_update_duty(LEDC_LOW_SPEED_MODE, motor->channel);

    motor->speed = (dir_a ? speed : -speed);

    return ESP_OK;
}

esp_err_t motor_stop(motor_t *motor)
{
    return set_motor_speed(motor, 0);
}

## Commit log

2026-06-01 initial commit with IMU proof of concept
2026-06-21 initial testing setup
    [partitions.csv]
2026-08-13 added hardware files (CAD STEP and PCB) and updated readme
    [AS5600.kicad_pcb, AS5600.kicad_sch, BMI320.kicad_pcb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]
2026-08-13 Updated readme for wiring clarity
2026-08-16 Added BOM and finialized main schematic.
    [BMI320.kicad_sch, BOM.csv, Liquorice_PCB.kicad_pcb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]
2026-08-18 updated readme to contain demo video and future wiring diagram
    [BOM.csv, Liquorice_PCB.kicad_pcb]
2026-08-18 Finalized PCB schematic and layout
    [Liquorice_PCB.kicad_pcb, Liquorice_PCB.kicad_sch]
2026-08-18 updated readme BOM
2026-08-22 finished PCBs and worked on BOM
    [AS5600-B_Cu.gbr, AS5600-B_Mask.gbr, AS5600-B_Paste.gbr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]
